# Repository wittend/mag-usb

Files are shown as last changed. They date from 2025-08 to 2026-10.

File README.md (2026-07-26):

# mag-usb

Version: 0.0.9

Official documentation -- https://mag-usb.readthedocs.io/

**mag-usb** is a Linux command‑line utility for reading a PNI RM3100 3‑axis magnetometer via a USB‑to‑I²C adapter (Pololu 5396/5397). It outputs time‑stamped magnetic field vectors and supports optional configuration via a simple TOML file.

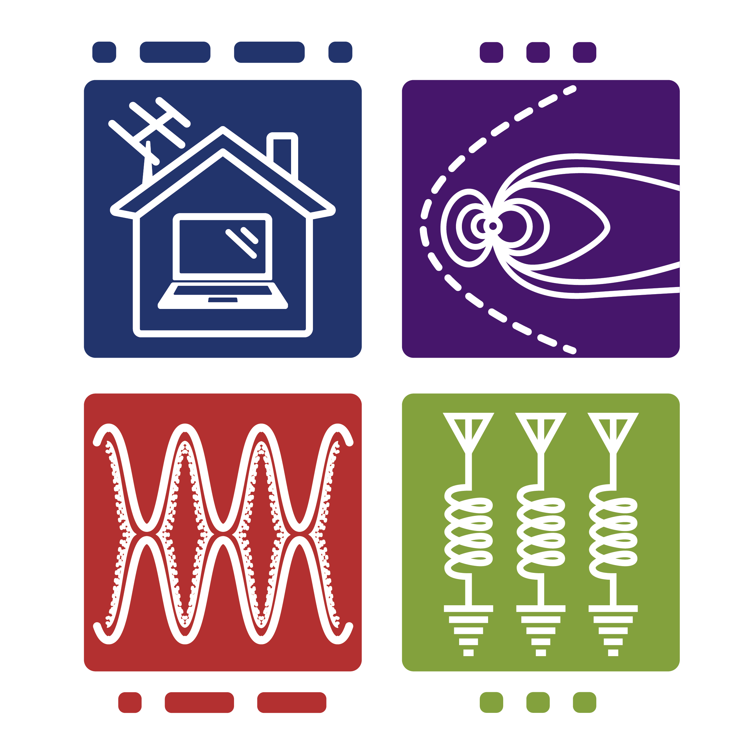
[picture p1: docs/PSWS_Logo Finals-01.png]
HamSCI Project


The RM3100 boards were developed for the HamSCI Personal Space Weather Station (PSWS) TangerineSDR and Grape monitors, but mag-usb can be used as a standalone low‑cost geomagnetic field logger.

Key points:
- Portable C (no heavyweight dependencies).
- Designed to use the Pololu Isolated USB‑to‑I²C Adapter family.
- Works on typical Linux hosts with USB 2.0. Raspberry Pi‑class devices may work but are not the current target.
- Windows is not supported. MacOS is supported through Docker.

## Features
- Reads RM3100 magnetometer X/Y/Z and prints JSON lines including an RFC‑2822 timestamp.
- Configurable cycle counts, gains, and sampling parameters.
- Optional orientation translations in 90° increments about X/Y/Z, set in config.toml.
- Support for concurrent output to `stdout` and named pipes for IPC (local monitoring/dashboards).
- MQTT publication support (1Hz batched JSON) with TLS and authentication.
- Convenience flag to print current settings (`-P`).
- Optional diagnostics: verify devices, scan I²C bus, etc.

## Build (using CMake)

Plain CMake (requires OpenSSL):
```
cmake -S . -B build -DCMAKE_BUILD_TYPE=Release
cmake --build build --target mag-usb
```

Optional WebSocket support (vendored header-only library):
```
cmake -S . -B build -DCMAKE_BUILD_TYPE=Release -DENABLE_WEBSOCKET=ON
cmake --build build --target mag-usb
```

CLion IDE (convenient if you happen to have it):
- Open the project; CLion generates Debug and Release profiles under cmake-build-debug and cmake-build-release.
- Build the target `mag-usb` from the chosen profile.

## Build (using Docker)
Use socat to create a connection to the adapter. Then, start a container:
```
docker compose run --rm host
```

Refer to the [setup documentation](/docs/MacOS-Setup.md) for more details.

## Quick start
- Connect the Pololu USB‑to‑I²C adapter and your RM3100 board.
- Install the udev rule from `install/99-PololuI2C.rules` once per host
  so the adapter consistently appears as `/dev/ttyMAG0` (the new
  default). Without the rule, override with `-O /dev/ttyACM0` (or
  whichever ACM device the adapter enumerated as).
```
./build/mag-usb -Q                # uses /dev/ttyMAG0 by default
./build/mag-usb -O /dev/ttyACM0 -Q  # override if no udev rule
```
Flags shown here:
- `-O` sets the adapter device path.
- `-Q` verifies adapter presence.

To print current settings (and exit):
```
./build/mag-usb -P
```
The program follows Linux filesystem conventions and looks for its configuration file in the following order:
1. `/etc/mag-usb/config.toml`
2. `config.toml` in the current working directory.

If neither is found, reasonable default values are used. Command-line arguments always overrule both default values and those found in any configuration file.

## Configuration
A simple TOML configuration file is supported. The program searches for it in `/etc/mag-usb/config.toml` first, then in the local directory. See:
- docs/Configuration.md — all keys, defaults, and examples.
- docs/Orientation-and-Axes.md — how the 90° orientation translations work.

Example orientation section:
```
[mag_orientation]
mag_translate_x = 90
mag_translate_y = 0
mag_translate_z = -90
```
Allowed values: `-180, -90, 0, 90, 180` (±180 are equivalent). Invalid/missing values default to 0.

## Output format
Each line is JSON with at least:
```
{ "ts": "DD Mon YYYY HH:MM:SS", "rt": NN.NNN, "x": NNN.NNN, "y": NNN.NNN, "z": NNN.NNN }
```
- Units: nanoTesla (nT)
- Orientation translations are applied before printing.
See docs/Data-Format.md for more detail.

## Running tests (CTest)
The `i2c-pololu` unit tests are integrated with CTest.

Enable/Build/Run:
```
cmake -S . -B build -DBUILD_TESTING=ON
cmake --build build --target i2c-pololu-tests
(cd build && ctest --output-on-failure)
```
Run the test executable directly:
```
./build/i2c-pololu-tests
```

## Documentation
- Getting Started: docs/Getting-Started.md
- Configuration reference: docs/Configuration.md
- MQTT Testing Tools: tools/mqtt_listener.c, tools/mqtt_command.c
- Orientation and axes: docs/Orientation-and-Axes.md
- Data format: docs/Data-Format.md
- Hardware Setup (wiring, udev rules): docs/Hardware-Setup.md
- Requirements: docs/Requirements.md
- Troubleshooting: docs/Troubleshooting.md
- Project Review: docs/Code-Review-and-Critique-2026-05-15-by-gemini-3-flash-preview.md
- Development guide: docs/Development.md
- Contributors: docs/Contributors.md
- Contribution guidelines: CONTRIBUTING.md

## Command‑line help
```
./mag-usb -h
```
You should see something similar to:
```
Parameters:

   -B <reg mask>          :  Do built in self test (BIST).         [ Not implemented ]
   -C                     :  Read back cycle count registers before sampling.
   -c <count>             :  Set cycle counts as integer.          [ default: 200 decimal]
   -D <rate>              :  Set magnetometer sample rate.         [ TMRC reg 96 hex default ].
   -g <mode>              :  Device sampling mode.                 [ POLL=0 (default), CONTINUOUS=1 ]
   -O                     :  Path to Pololu port in /dev.          [ default: /dev/ttyACM0 ]
   -P                     :  Show all current settings and exit.
   -Q                     :  Verify presence of Pololu adaptor.
   -S                     :  List devices seen on i2c bus and exit.
   -T                     :  Verify Temperature sensor presence and version.
   -u                     :  Use named pipes for output.
   -i <path>              :  Path for input named pipe.
   -o <path>              :  Path for output named pipe.
   -V                     :  Display software version and exit.
   -h or -?               :  Display this help.
```

## Contributors
- **Dave Witten, KD0EAG** - Lead developer and maintainer.
- **Michael Hauen** - Contribution to sample reliability and code quality.
- **Jackson Conti** - Core contributions and implementation.
- **Bill Engelke** - Improvement to output timing and cadence.
- **Dave Larsen** - Formatting and JSON output enhancements.
- **Rob** - Integration and system testing support.
- **Claude (AI)** - Code reviews and project architecture guidance.
- **Gemini (AI)** - Development of MQTT capabilities, documentation, and technical critiques.

## Pololu adapter links
- https://www.pololu.com/product/5397
- https://www.pololu.com/product/5396

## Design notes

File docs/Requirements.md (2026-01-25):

# mag-usb Requirements

This document defines the functional, non-functional, and delivery requirements for a clean-room reimplementation of the mag-usb project.
It is a specification document, not an implementation guide.
It is intended as a start-to-finish blueprint: hardware, software, build, runtime behavior, and documentation.

## 1. Scope and goals
- Provide a Linux command-line utility that reads a PNI RM3100 3-axis magnetometer via a Pololu USB-to-I2C adapter.
- Emit time-stamped magnetic field vectors in a JSON-lines format for downstream ingestion.
- Support a simple TOML configuration file, with command-line overrides.
- Provide lightweight diagnostics (adapter check, I2C bus scan, sensor presence checks).
- Keep implementation portable C (C11) with minimal dependencies.

Non-goals:
- Windows support.
- Arbitrary-angle orientation or full magnetometer calibration (soft/hard iron compensation).
- GUI or web interface.

## 2. Supported platforms and environment
- Target OS: Linux.
- Expected device nodes: USB CDC ACM (`/dev/ttyACM*`).
- macOS: untested and optional.
- SBCs (Raspberry Pi class): not primary target; use Pololu adapter instead of native GPIO/I2C libraries.

## 3. Hardware requirements
- Pololu Isolated USB-to-I2C Adapter:
  - Product 5396 or 5397.
- RM3100-based magnetometer board.
- Wiring:
  - SDA to SDA, SCL to SCL, GND to GND, optional +5V if required by board.
  - Confirm I2C pull-ups exist.
- Optional: MCP9808 temperature sensor for remote temperature readings.

## 4. System behavior and functional requirements

### 4.1 Program startup
- Load defaults for all parameters.
- Load configuration file from:
  1) `/etc/mag-usb/config.toml`
  2) `config.toml` in current working directory
- If the first file fails to load or does not exist, fall back to local file.
- Ignore or clamp invalid config values to defaults.
- Parse command-line arguments after config load; CLI overrides config and defaults.
- If `-P` is passed, print active settings and exit before hardware initialization.

### 4.2 Command-line interface (CLI)
Provide the following options:
- `-B <reg mask>`: BIST (not implemented, but option exists).
- `-C`: read back cycle count registers before sampling.
- `-c <count>`: set cycle count for X/Y/Z; valid range 1..800 (decimal).
- `-D <rate>`: set CMM sample rate (integer).
- `-g <mode>`: sampling mode (POLL=0, CMM=1).
- `-O <path>`: Pololu adapter device path (default `/dev/ttyACM0`).
- `-P`: show current settings and exit.
- `-Q`: verify Pololu adapter presence and exit.
- `-M`: verify magnetometer presence and version and exit.
- `-S`: scan I2C bus and exit.
- `-T`: verify temperature sensor presence and version and exit.
- `-u`: enable named pipes for output.
- `-i <path>`: input named pipe path.
- `-o <path>`: output named pipe path.
- `-V`: print version and exit.
- `-h`/`-?`: print help and exit.

### 4.3 I2C adapter handling
- Verify adapter availability at the configured device path with timeout.
- Validate adapter is a supported Pololu device.
- If adapter is missing or invalid, exit with a clear error.
- If `-Q` is set, only validate adapter and exit 0/1.

### 4.4 Sensor handling
- Support RM3100 magnetometer at a configurable I2C address (default from build config).
- Support MCP9808 temperature sensor at configurable I2C address (default 0x1F).
- Provide diagnostic checks:
  - `-M`: verify magnetometer.
  - `-T`: verify temperature sensor.
  - `-S`: scan I2C bus and report devices.
- Initialize magnetometer registers before sampling.

### 4.5 Sampling and output
- Primary data output: JSON lines, one per sample.
- Output schema:
  - `ts` (string): UTC timestamp, format `DD Mon YYYY HH:MM:SS` (RFC-2822-like without timezone).
  - `rt` (number): remote temperature in deg C.
  - `x`, `y`, `z` (number): magnetometer values in nT, formatted with 3 decimal places.
- Convert RM3100 raw counts to microTesla then multiply by 1000 to nT.
- Apply orientation rotations (see 4.6) before output.
- Log and diagnostic messages may be interleaved with JSON lines on the same stream.

### 4.6 Orientation rotations
- Support 90-degree increments about X, Y, Z axes using right-hand rule.
- Allowed values: -180, -90, 0, 90, 180.
- Apply rotations in order X, then Y, then Z.
- Invalid values fall back to 0.

### 4.7 Named pipes and logging
- If `use_pipes` is enabled or `-u` flag is provided:
  - Create FIFOs if missing with mode 0666.
  - Default paths (from sample config):
    - Input: `/run/mag-usb/magctl.fifo`
    - Output: `/run/mag-usb/magdata.fifo`
  - Open output pipe as non-blocking write, input as non-blocking read.
- If `write_logs` is enabled:
  - Write JSON lines to log files in `log_output_path`.
  - Create directory if `create_log_path_if_empty` is true.

### 4.8 WebSocket output (optional)
- Provide a build flag `ENABLE_WEBSOCKET` to include WebSocket server support.
- When enabled and configured, broadcast each JSON output line to all connected clients.
- Allow runtime configuration of bind address and port.
- Accept multiple concurrent clients; send text frames.

### 4.9 Configuration keys
TOML sections and keys to support:

[node_information]
- `maintainer` (string)
- `maintainer_email` (string)

[node_location]
- `latitude` (string)
- `longitude` (string)
- `elevation` (string)
- `grid_square` (string)

[i2c]
- `use_I2C_converter` (bool)
- `portpath` (string)
- `bus_number` (int)
- `scan_bus` (bool)

[magnetometer]
- `address` (int, decimal or hex)
- `cc_x`, `cc_y`, `cc_z` (int)
- `gain_x`, `gain_y`, `gain_z` (double)
- `tmrc_rate` (int, decimal or hex)
- `nos_reg_value` (int)
- `drdy_delay` (int)
- `sampling_mode` (string "POLL" or "CMM")
- `cmm_sample_rate` (int)
- `readback_cc_regs` (bool)

[mag_orientation]
- `mag_translate_x`, `mag_translate_y`, `mag_translate_z` (int)

[temperature]
- `remote_temp_address` (int, decimal or hex)

[output]
- `write_logs` (bool)
- `log_output_path` (string)
- `create_log_path_if_empty` (bool)
- `use_pipes` (bool)
- `pipe_in_path` (string)
- `pipe_out_path` (string)

[websocket]
- `enable` (bool)
- `bind_address` (string)
- `port` (int)

## 5. Non-functional requirements
- Language: C11; avoid compiler-specific extensions without guards.
- Dependencies: none beyond standard POSIX/Linux system libraries.
- Build tooling: CMake 3.22+.
- Warnings: build with `-Wall -Wextra -Wpedantic`; allow optional `-Werror`.
- Runtime stability: exit with meaningful error messages for adapter/sensor failures.
- Performance: stable sampling, acknowledging jitter from host scheduling and JSON printing.

## 6. Build, test, and packaging

### 6.1 Build
- Provide a top-level `CMakeLists.txt`.
- Build targets:
  - `mag-usb` (main CLI).
  - `i2c-pololu-tests` (unit tests).
- Provide Debug/Release builds via CMake or IDEs (e.g., CLion).

### 6.2 Tests
- Integrate unit tests with CTest.
- Command line:
  - `cmake -S . -B build -DBUILD_TESTING=ON`
  - `cmake --build build --target i2c-pololu-tests`
  - `(cd build && ctest --output-on-failure)`

### 6.3 Installation artifacts
- Include a sample `config.toml`.
- Provide udev rule for Pololu adapter in `install/99-PololuI2C.rules`.
- Document installation of udev rule and permissions.

## 7. Documentation deliverables
Required documentation pages:
- Getting started and build steps.
- Hardware wiring and udev setup.
- Configuration reference and examples.
- Output data format.
- Orientation and axes explanation.
- Troubleshooting guide.
- Development guide (build matrix and coding patterns).

## 8. Acceptance criteria
- Build succeeds with CMake 3.22+ on Linux using GCC or Clang.
- `mag-usb -h` shows all documented CLI flags.
- `mag-usb -P` prints effective configuration values.
- `mag-usb -Q` validates adapter and exits.
- JSON output matches schema and units, with orientation rotations applied.
- Config file parsing and CLI overrides behave as specified.
- Named pipes and logging operate per configuration with correct permissions.
- Unit tests compile and run via CTest.

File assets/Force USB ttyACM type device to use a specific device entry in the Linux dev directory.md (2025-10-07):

## Force USB ttyACM to specific /dev device

Yes, there is a way in Linux to force a USB ttyACM type device to always attach to a specific device file in /dev by using udev rules to create persistent symbolic links This ensures that the device is consistently accessible under a predictable name, regardless of the order in which devices are connected or the system's boot sequence.

To achieve this, you need to create a custom udev rule file in the /etc/udev/rules.d/ directory, such as /etc/udev/rules.d/49-custom.rules The rule should identify the specific USB device using unique attributes like the vendor ID (`idVendor`) and product ID (`idProduct`) obtained from `lsusb` For example, to assign a U-Blox GNSS receiver to a symbolic link named `/dev/ttyGPS`, the rule would be:

```
KERNEL=="ttyACM[0-9]*", SUBSYSTEM=="tty", ATTRS{idVendor}=="1546", ATTRS{idProduct}=="01a8", SYMLINK+="ttyGPS"
```

This rule uses the `SYMLINK` directive to create a persistent symbolic link that points to the actual device file (e.g., `/dev/ttyACM0` or `/dev/ttyACM1`) After creating the rule, reload the udev rules with `udevadm control --reload-rules` and reboot the system to apply the changes Once configured, services or applications can reference the consistent symbolic name (e.g., `/dev/ttyGPS`) instead of relying on the potentially changing `/dev/ttyACM*` name

If multiple devices share the same `idVendor` and `idProduct`, you can use additional unique attributes such as the device's serial number (`ATTRS{serial}`) or its kernel path (`KERNELS`) to distinguish them For instance, using `KERNELS=="1-4:1.0"` can tie the rule to a specific USB port on a hub, ensuring consistent naming even when multiple devices are present

## Elaboration

To force a USB ttyACM device to always appear under a specific name in `/dev`, you can create a **persistent symbolic link** using **udev rules** based on unique device attributes.

### 1. Identify Unique Device Attributes
First, connect the device and use:
```bash
udevadm info --name=/dev/ttyACM0 --attribute-walk
```
Look for stable, unique identifiers such as:
- `idVendor` and `idProduct` (identifies device type)
- `serial` (unique per device)
- `KERNELS` (e.g., `1-4:1.0` — identifies physical USB port)

### 2. Create a udev Rule
Create a rule file:
```bash
sudo nano /etc/udev/rules.d/99-mydevice.rules
```

#### Example Rules:
- **By vendor/product (for single device of this type):**
  ```
  SUBSYSTEM=="tty", KERNEL=="ttyACM[0-9]*", ATTRS{idVendor}=="1546", ATTRS{idProduct}=="01a8", SYMLINK+="ttyGPS"
  ```

- **By serial number (for multiple identical devices):**
  ```
  SUBSYSTEM=="tty", KERNEL=="ttyACM[0-9]*", ATTRS{serial}=="ABC123", SYMLINK+="ttyGPS1"
  ```

- **By physical USB port (assigns name based on plug-in location):**
  ```
  SUBSYSTEM=="tty", KERNEL=="ttyACM[0-9]*", KERNELS=="1-4:1.0", SYMLINK+="ttyGPS"
  ```

### 3. Reload and Test
Apply the rules:
```bash
sudo udevadm control --reload-rules && sudo udevadm trigger
```
Replug the device and verify:
```bash
ls -l /dev/ttyGPS
```

### Key Notes:
- Use `SYMLINK+="name"` to create a persistent alias like `/dev/ttyGPS`.
- For multiple similar devices, **use `serial` or `KERNELS`** to avoid conflicts.
- The rule file should end with `.rules` and ideally start with a high number (e.g., `99-`) to ensure it runs last.
- Ensure the file has a trailing newline and is owned by root.

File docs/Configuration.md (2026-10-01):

# Configuration

mag-usb reads an optional `config.toml` at startup. It searches for the configuration file in the following order:
1. `/etc/mag-usb/config.toml` 
2. `config.toml` in the current working directory.

If neither file is found, defaults are used. Invalid values are ignored or reduced to defaults. Command-line arguments always override both default values and those found in any configuration file.

Tip: Run `./mag-usb -P` to print the active settings and exit.

## File format
- Syntax: TOML (key = value). Lines beginning with `#` are comments.
- Sections use `[section_name]` headers.
 
## Sections and keys
Below is the complete reference of supported sections/keys, their types, defaults, and notes.

### [node_information]
- `maintainer` (string)
- `maintainer_email` (string)

Defaults: empty strings.

### [node_location]
- `latitude` (string) — free‑form (e.g., "38.92263").
- `longitude` (string)
- `elevation` (string) — free‑form (e.g., "230 m").
- `grid_square` (string) — e.g., "EM38uw".

Defaults: empty strings.

### [i2c]
- `use_I2C_converter` (bool) — Use Pololu USB‑to‑I²C adapter. Default: true (when built with USE_POLOLU=TRUE).
- `portpath` (string) — Adapter device path. Default: `/dev/ttyMAG0` (created by `install/99-PololuI2C.rules`; falls through to a bare `/dev/ttyACM*` if the udev rule is not installed and `-O` is not supplied).
- `bus_number` (int) — Linux I²C bus number for non‑Pololu setups. Default: 1.
- `scan_bus` (bool) — Probe for devices on startup. Default: false.

Notes:
- If `use_I2C_converter=true`, `portpath` must be accessible to the process (see udev notes in Hardware‑Setup.md).

### [magnetometer]
- `address` (int, decimal or hex `0xNN`) — RM3100 I²C address. Default: build‑time default from `RM3100_I2C_ADDRESS`.
- `cc_x`, `cc_y`, `cc_z` (int) — Cycle counts. Typical values: 200, 400. Default: 400 (if set in config.toml).
- `gain_x`, `gain_y`, `gain_z` — No longer used. The gain is derived from each axis's cycle count (`gain = 0.3671 × CC + 1.5`, e.g. 148.34 at CC 400), so it always matches what the sensor is programmed with. If these keys are present, a warning is printed and they are ignored.
- `tmrc_rate` (int, decimal or hex) — TMRC register value. Default: 0x96.
- `nos_reg_value` (int) — Number‑of‑samples register value. Default: 60.
- `drdy_delay` (int) — Sleep between DRDY-poll iterations in **milliseconds**. Default: 10. (The implementation passes `drdy_delay * 1000` to `usleep()`, which takes microseconds; the configured value is therefore an `ms` count, not a `µs` count.)
- `sampling_mode` (string) — `"POLL"` or `"CMM"`. Default: `"POLL"`.
- `cmm_sample_rate` (int) — CMM sample rate (Hz). Default: 400.
- `readback_cc_regs` (bool) — Read back CC registers after setting. Default: false.

### [mag_orientation]
Defines fixed 90°‑increment rotations applied to the measured vector before printing.
- `mag_translate_x` (int) — Allowed values: -180, -90, 0, 90, 180.
- `mag_translate_y` (int) — Allowed values: -180, -90, 0, 90, 180.
- `mag_translate_z` (int) — Allowed values: -180, -90, 0, 90, 180.

Rules:
- Missing/invalid values default to 0.
- `180` and `-180` are treated equivalently.
- Rotations are applied in the order X, then Y, then Z, using right‑hand rule conventions.
- See Orientation-and-Axes.md for visuals and examples.

### [temperature]
- `remote_temp_address` (int, decimal or hex) — MCP9808 temperature sensor address. Default: 0x1F.

### [mqtt]
- `enable` (bool) — Enable MQTT publication. Default: false.
- `broker_address` (string) — MQTT broker host. Default: `localhost`.
- `broker_port` (int) — MQTT broker port. Default: 8883.
- `username` (string) — Optional username.
- `password` (string) — Optional password.
- `topic` (string) — Publication topic. Default: `mag-usb/data`.
- `client_id` (string) — Client ID. Default: `mag-usb-client`.
- `use_tls` (bool) — Use secure TLS (mqtts://). The broker's certificate is verified, and the connection is refused if verification fails. Default: true.
- `ca_file` (string) — Path to a PEM CA certificate (or bundle) used to verify the broker. Empty uses the system trust store, which covers brokers with certificates from a public CA. Set it for a self-signed or private-CA broker. Default: empty.

TLS verification also checks that the broker's certificate names the host in `broker_address`: a DNS name is matched against the certificate's DNS names, and an IP address against its IP addresses. If the connection fails, the error printed on stderr says why (for example `unable to get local issuer certificate` means the CA isn't trusted, so set `ca_file`).

Note: Credentials (username/password) are never included in the JSON configuration messages published to the topic.
Commands like `get_config` can be sent to `<topic>/command` to trigger a re-broadcast of the current settings.

### [output]
- `write_logs` (bool) — Write logs to files. Default: false.
- `log_output_path` (string) — Path for log files. Default: `./logs` (when logging enabled).
- `create_log_path_if_empty` (bool) — Create `log_output_path` if missing. Default: true.
- `use_pipes` (bool) — Use named pipes for IPC. Default: false.
- `pipe_in_path` (string) — Path to control pipe (writer side). Default: `/run/mag-usb/magctl.fifo`.
- `pipe_out_path` (string) — Path to data pipe (reader side). Default: `/run/mag-usb/magdata.fifo`.

Note: When `use_pipes=true`, the program will create the pipes if they do not exist with `0666` permissions.

### [websocket]
- `enable` (bool) — Enable the WebSocket output server. Default: false.
- `bind_address` (string) — Server bind address. Default: `0.0.0.0`.
- `port` (int) — Server port. Default: 8765.
Note: This section is active only when built with `-DENABLE_WEBSOCKET=ON`.

## Example
```toml
# mag-usb Configuration File
# Lines starting with # are comments.
# Inline comments (Data followed by hashmark) not allowed.
[node_information]
maintainer = "Dave Witten, KD0EAG"
maintainer_email = "wittend@wwrinc.com"

[node_location]
# Tools:
#   lat/long: Google Maps or GNSS device.
#   Altitude: Optional, or Use GNSS device, or find yourself in Google Earth and look at the status bar at the bottom.
#   Grid square conversion: https://www.giangrandi.org/electronics/radio/qthloccalc.shtml or similar.
latitude = "38.92263"
longitude = "-92.29831"
elevation = "230 M"
grid_square = "EM38uw"

[output]
# Write logfiles to log_output_path..
write_logs = false
# create logfiles in this location.
log_output_path = "./logs"
# create this location if it does not esist.
create_log_path_if_empty = true

# Use named pipes for IPC.
use_pipes = false
# Pipe paths (if use_pipes is true).
pipe_in_path = "/run/mag-usb/magctl.fifo"
pipe_out_path = "/run/mag-usb/magdata.fifo"

[websocket]
# Enable WebSocket output server.
enable = false
# Bind address and port for WebSocket clients.
bind_address = "0.0.0.0"
port = 8765

[i2c]
# Use external USB to I2C device.
use_I2C_converter = true
# Path to the I2C device.
portpath = "/dev/ttyMAG0"
# I2C bus number (for non-Pololu setups).
bus_number = 1
# Scan I2C bus on startup.
scan_bus = false

[magnetometer]
# Magnetometer I2C address (hex format supported).
address = 0x23
# Cycle Count registers (200 or 400 typically).
cc_x = 400
cc_y = 400
cc_z = 400
# Gain is derived from the cycle count: gain = 0.3671 * CC + 1.5.
# TMRC Rate register value (hex format).
tmrc_rate = 0x96
# Number of samples register value.
nos_reg_value = 60
# DRDY delay in milliseconds (passed to usleep as ms * 1000).
drdy_delay = 10
# Sampling mode: "POLL" or "CMM".
sampling_mode = "POLL"
# CMM sample rate (Hz)
cmm_sample_rate = 400
# Read back cycle count registers after setting.
readback_cc_regs = false

# Magnetometer Orientation in degrees relative to default (See hardware setup docs).
# Plus and minus 180 are equivalent. Plus and minus 90 are different!
[mag_orientation]
# Allowed values: -180, -90, 0, 90, 180
mag_translate_x = 0
mag_translate_y = 0
mag_translate_z = 0

[mqtt]
# Enable MQTT publication.
enable = false
# Broker address and port (use 8883 for TLS/MQTTS).
broker_address = "localhost"
broker_port = 8883
# Optional credentials.
username = ""
password = ""
# Topic for data publication.
topic = "mag-usb/data"
client_id = "mag-usb-client"
# Use secure TLS (mqtts://). The broker's certificate is verified.
use_tls = true
# CA certificate for a self-signed or private-CA broker (empty = system trust store).
ca_file = ""

[temperature]
# Remote temperature sensor I2C address
remote_temp_address = 0x1F
```

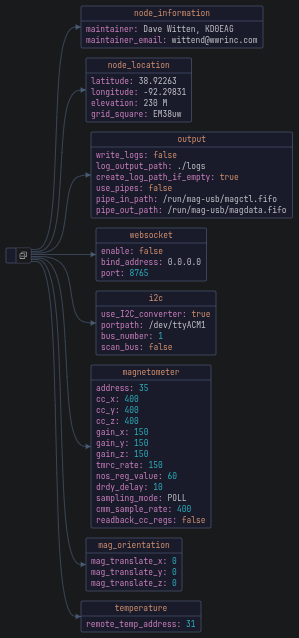
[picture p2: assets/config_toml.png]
Configuration Example

*Fig. 3: Sample config.toml file for mag-usb.*

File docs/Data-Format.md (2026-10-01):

# Data Format

mag-usb prints one JSON object per line to OUTPUT_PRINT. Each line represents a single sample of the magnetometer vector (and optionally other values in the future).

## Baseline schema
```
{ "ts": "DD Mon YYYY HH:MM:SS", "rt": <float>, "x": <float>, "y": <float>, "z": <float> }
```
- `ts` (string): UTC timestamp formatted like `25 Oct 2025 14:02:33` (RFC‑2822‑like time portion without timezone offset).
- `rt` (number): Value of temperature measured in degree C of the sensor at its 'remote' location. 
- `x`, `y`, `z` (number): Field components in nanoTesla (nT), with 3 decimal places printed.

Example:
```
{ "ts":"26 Oct 2025 14:20:00", "rt":23.125, "x":12345.678, "y":-234.500, "z":987.001 }
```

## Units and scaling
- Raw RM3100 counts are converted using the gain for each axis's cycle count (`gain = 0.3671 × CC + 1.5`) and the `NOS` (number‑of‑samples) register value.
- Outputs are provided in nanoTesla (nT). Internally the computation converts microTesla to nanoTesla by multiplying by 1000.

## Orientation translations
If configured, 90° increment rotations are applied to `(x,y,z)` before printing. See `docs/Orientation-and-Axes.md` and `[mag_orientation]` in `docs/Configuration.md`.

## Precision and rounding
- Values are printed with `%.3f` (three digits after decimal). This does not imply instrument accuracy; it is a display choice.

## Sampling cadence
- In POLL mode, each call to `formatOutput()` prints one sample.
- In CMM mode (continuous), the sample rate is controlled by `cmm_sample_rate`; see `docs/Configuration.md`.

## Errors and diagnostics output
- Informational and error messages (e.g., adapter checks) are printed to OUTPUT_PRINT/ around the JSON lines. If you need a clean stream of JSON only, redirect  and/or prefilter lines not starting with `{`.

## MQTT Message Formats

When MQTT is enabled, two types of messages are published to the configured topic.

### 1. Telemetry Data (1Hz Batched)
By default, sensor readings are batched and published once per second to minimize network overhead and avoid timing overlaps.
```json
{
  "ts": "26 Jul 2026 14:20:01",
  "rt": 23.125,
  "x": 12345.678,
  "y": -234.500,
  "z": 987.001
}
```

### 2. Configuration Message
Published automatically on connection, and whenever a `get_config` command is received on the `<topic>/command` sub-topic.
```json
{
  "msg_type": "config",
  "version": "0.0.9",
  "maintainer": "Dave Witten, KD0EAG",
  "location": {
    "lat": "38.92263",
    "lon": "-92.29831",
    "grid": "EM38uw"
  },
  "mqtt_settings": {
    "broker": "test.mosquitto.org",
    "port": 8883,
    "topic": "mag-usb/data",
    "tls": true
  }
}
```
**Note:** Sensitive information such as the MQTT password is never included in the configuration message.

## Logging and pipes
- If you enable logging or named pipes in the configuration, the same JSON lines are written to files or pipes. 
- Named pipes (FIFOs) allow real-time IPC with local monitor/dashboard programs.
- Default pipe paths are `/run/mag-usb/magctl.fifo` (input) and `/run/mag-usb/magdata.fifo` (output).
- See `docs/Configuration.md` (output section) for details.

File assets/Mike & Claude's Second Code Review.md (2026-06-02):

## Second Claude Code Review for mag-usb. 
Focused on the scaling and configuration issues that have been observed in live data.

1. [**Note**: This is a follow-up to the first Claude code review, which focused on code quality and maintainability. This review focuses on correctness and operator experience.]
2. [**Note**: A second review using the Gemini model was performed to examine standalone code quality and maintainability, without the context of the live data issues. That review is documented separately.]
3. [**Note**: This represents feedback within a team consisting of three humans: Mike, Rob, and Dave.  Dave is the author of the code under review, and Rob is a third team member working with Mike. Claude, Gemini, and their friends are AI Assistants.  Claude is providing objective feedback. Dave is also being assisted by one of more AI tools.]
4. [**Note**: Mike, Rob, and Claude are working together to integrate this program (mag-usb) into a larger system (sigmond), that may also incorporate other components (mag-recorder, magrec, a global installation process, etc.) when used with sigmond.]
5. [**Note**: mag-usb must also retain the ability to be configured independently.]
6. [**Note**: The tone is collaborative and constructive, with a focus on improving the code and the operator experience.]

### PR-1: drop the spurious /NOSRegValue factor in POLL-mode scaling

src/main.c:606-608:
* xyz[0] = (((double)p->XYZ[0] / p->NOSRegValue) / p->x_gain) * 1000;
* The PNI formula Dave himself pasted into src/magdata.c:142-148 is µT = raw / (0.3671·CC + 1.5), no NOS term. With NOSRegValue defaulting to 60, every reported value is off by ~60× — that's exactly what live data on my desk shows (-210..+412
where Earth-field axis components should be 10,000–30,000 nT). NOS only belongs in the scaling for CMM-with-averaging, where the chip has been programmed to sum N samples internally; in single-shot POLL mode the chip already returns per-sample values. 
* Suggested fix: drop the /NOSRegValue. If Dave wants to keep an averaging path for a future CMM mode, gate it on p->samplingMode == CMM and only when the chip's NOS register has actually been written.

### PR-2: actually program the chip's CC and NOS registers (or remove the knobs)

src/magdata.c:166-180 (setCycleCountRegs) 
* has every i2c_write commented out. 
* Same in setNOSReg at magdata.c:106-114: 
    * the whole body is dead. Net effect: cc_x/y/z and NOSRegValue in config are host-side ghosts. The chip stays at power-on
defaults (CC=200/axis), and any operator who edits cc_x = 400 in tools/config.toml thinks they've doubled their sensitivity but actually they've just made the host divide by a bigger number. This is upstream of the magnitude bug in PR-1 — both
fixes are needed.

Chosen approach:
* Restore the writes using the Pololu I²C path (the rest of the I/O in this binary already does this), so config takes effect. Cleaner long-term.
* **Make note** in _documentation_ and _comment in code_: "[**Path not taken**]: remove the host-side CC/NOS knobs entirely, hard-code gain from chip defaults, and document that. Smaller patch, less flexible."

Either is fine; the current limbo is what's broken.

### PR-3: fix the example tools/config.toml

tools/config.toml ships cc_x = cc_y = cc_z = 400
* This combined with PR-2 silently mis-scales. After PR-2 lands this becomes a correctness fix or a delete-the-knob change, depending on which path Dave picks.

* mag-usb layering PRs (so mag-recorder can fully own operator config)

* The pattern I'd like to align with: mag-recorder is the program the operator configures; mag-usb is the sensor driver mag-recorder drives. Operator never sees /etc/mag-usb/anything. All knobs live in /etc/mag-recorder/mag-recorder-config.toml.

### PR-4: accept config-file path on the CLI

src/main.c currently auto-discovers /etc/mag-usb/config.toml then ./config.toml, with no way to point it elsewhere. 
* Make it accept -f <path> (or --config <path> if Dave wants to move to getopt_long) — note -c is already taken by cycle-count.
* When -f is given, skip the auto-discovery entirely so the binary's behavior is fully determined by argv. 
    - mag-recorder will then render a private TOML at /etc/mag-recorder/mag-usb-driver.toml and pass it explicitly.

Optional sweetener: also accept -A <hex> (single-knob address override) for the common case of "everything else default, just point at 0x23." Saves a config file in the hand-debug workflow.

### PR-5: make -P (show settings) print chip state, not host state

Today -P prints the host's intended values. After PR-2 those should match the chip, but a real -P that reads back the CC/NOS/TMRC registers would catch any future regression where the writes silently stop landing. Small but high-leverage.

What this lets mag-recorder do (no Dave work, just queued on our side)

1. Render /etc/mag-recorder/mag-usb-driver.toml as an install step — sourced from [mag] keys in mag-recorder-config.toml. Operator never edits the driver TOML.
2. Patch supervisor.py:_mag_usb_source to construct argv = [binary, "-O", device, "-f", "/etc/mag-recorder/mag-usb-driver.toml"]. The currently-dangling mag_usb_config key in mag-recorder-config.toml finally connects to something.
3. Add an install step that drops install/99-PololuI2C.rules from upstream mag-usb into /etc/udev/rules.d/ and runs udevadm trigger. This is the "predictable device regardless of USB port" piece — /dev/ttyMAG0 becomes the stable symlink
   mag-recorder's config already points at by default.
4. Add magrec to dialout in deploy (already done in the service file's SupplementaryGroups=dialout; confirm the user-creation step also sets it).
5. Strengthen mag-recorder validate to fail loudly when the configured [mag].i2c_address doesn't match what mag-usb -M reports — so an operator with a different carrier-board strapping sees a clear
    validate error instead of a silent NACK at runtime.
Once PR-1+2+4 land in wittend/mag-usb (and we cherry-pick / merge into our sigmond-integration branch):

### PR-6: render /etc/mag-recorder/mag-usb-driver.toml from mag-recorder-config.toml

1. Render /etc/mag-recorder/mag-usb-driver.toml as an install step — sourced from [mag] keys in mag-recorder-config.toml. Operator never edits the driver TOML.
2. Patch supervisor.py:_mag_usb_source to construct argv = [binary, "-O", device, "-f", "/etc/mag-recorder/mag-usb-driver.toml"]. The currently-dangling mag_usb_config key in mag-recorder-config.toml finally connects to something.
3. Add an install step that drops install/99-PololuI2C.rules from upstream mag-usb into /etc/udev/rules.d/ and runs udevadm trigger. This is the "predictable device regardless of USB port" piece — /dev/ttyMAG0 becomes the stable symlink
   mag-recorder's config already points at by default.
4. Add magrec to dialout in deploy (already done in the service file's SupplementaryGroups=dialout; confirm the user-creation step also sets it).
5. Strengthen mag-recorder validate to fail loudly when the configured [mag].i2c_address doesn't match what mag-usb -M reports — so an operator with a different carrier-board strapping sees a clear validate error instead of a silent NACK at
   runtime.
6. Drop /etc/mag-usb/ from documentation entirely — README/PROVENANCE shouldn't mention it once PR-4 lands.

## Suggested order for your conversation with Dave

1. PR-1 (60× scaling — operator-visible correctness; this is the headline)
2. PR-2 (CC/NOS writes — explains why the scaling looks the way it does, and unblocks per-axis tuning)
3. PR-3 (example TOML — trivial follow-on)
4. PR-4 (config-file CLI flag — layering; this is the one that lets mag-recorder act like a proper sigmond client)
5. PR-5 (-P reads chip state — diagnostic hygiene)

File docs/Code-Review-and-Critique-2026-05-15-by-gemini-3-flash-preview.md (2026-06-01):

# Code Review and Critique - 2026-05-15  
### Project Critique and Code Review: `mag-usb`
###   by gemini-3-flash-preview
This document contains a comprehensive review of the `mag-usb` project performed on May 15, 2026, covering source code, build system, test suite, and documentation.

#### 1. Code Quality and Architecture
*   **Robust I²C Implementation**: The `i2c-pololu.c` module is exceptionally well-structured. It implements the Pololu binary protocol with clear error handling, device validation, and state management. The use of a mock device thread in tests demonstrates a high level of technical maturity.
*   **Thread Safety and Signals**: The project correctly uses POSIX threads (`pthreads`) and handles signals (`sigaction`, `sigwait`) to ensure graceful shutdowns. Blocking signals in worker threads and handling them in a dedicated thread is a best-practice pattern.
*   **Memory Management**: Strings parsed from the configuration are handled via `strdup` and freed in `free_config_strings`, indicating good hygiene regarding heap allocations.
*   **Configuration Parsing**: The custom TOML parser in `src/config.c` is functional and tailored to the project's needs. While it doesn't support the full TOML spec (e.g., nested tables or arrays), it is perfectly adequate for the current requirements.

#### 2. Build System and Portability
*   **Modern CMake**: The `CMakeLists.txt` is clean and follows modern practices. It uses `target_include_directories` and `target_compile_definitions` properly. The inclusion of `_GNU_SOURCE` and `_DEFAULT_SOURCE` ensures portability across Linux distributions.
*   **Conditional Features**: WebSocket support is correctly handled as an optional feature using CMake options and preprocessor definitions.
*   **Warning Hygiene**: Building with `-Wall -Wextra -Wpedantic` and having an `ENABLE_WERROR` option shows a commitment to code quality.

#### 3. Documentation
*   **Comprehensive Coverage**: The documentation in `docs/` is excellent. It covers everything from hardware wiring and udev rules to data formats and orientation theory.
*   **Visual Context**: The integration of images into the Markdown files significantly improves usability, especially for the hardware setup and troubleshooting sections.
*   **Consistency**: The `README.md` and the sub-docs are consistent in their instructions and reflect the current state of the CLI.

#### 4. Testing
*   **Effective Unit Tests**: The `i2c-pololu-tests` provide good coverage of the adapter communication logic. The use of `socketpair` to simulate a serial device is an elegant way to test hardware-interfacing code without physical hardware.
*   **Stability**: The tests pass reliably and include safety measures like an overall timeout (`alarm(30)`) to prevent hangs during CI/CD.

#### 5. Minor Observations / Areas for Improvement
*   **Configuration Path**: Currently, the program checks `/etc/mag-usb/config.toml` and then the local directory. Adding a flag to specify a custom config file path (e.g., `-c <path>`) would be a useful future enhancement.
*   **Inline Comments in TOML**: The parser currently ignores lines starting with `#` but might not handle inline comments (e.g., `key = value # comment`). This is noted in the documentation as a limitation.
*   **Hardware Defaults**: The code relies on some external `extern` variables for defaults (e.g., `CC_400`). Ensuring these are consistently initialized across all build profiles is important.

### Conclusion
The project is in a **very healthy state**. The code is professional, the build system is robust, the tests are effective, and the documentation is top-tier for an open-source utility.

**Review Result:** ✅ **Ready to commit and push.**

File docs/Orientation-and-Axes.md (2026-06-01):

# Orientation and Axes

This document explains how mag-usb handles magnetometer orientation and how to configure 90° rotations around each axis.

## Axis conventions
- The RM3100 outputs three orthogonal components X, Y, Z.
- mag-usb treats these axes as a right‑handed coordinate system.
- Positive rotations follow the right‑hand rule (thumb points along the axis of rotation; curl of fingers is direction of positive rotation).
 
## Why orientation adjustments?
Depending on how the sensor PCB is mounted in your enclosure, its axes may not align with your desired reference frame. mag-usb can rotate the measured vector by multiples of 90° around the X, Y, and Z axes to align with your installation.

## Configuration
Set the following keys in `config.toml` under `[mag_orientation]`:
```
[mag_orientation]
mag_translate_x = <int>   # -180, -90, 0, 90, 180
mag_translate_y = <int>   # -180, -90, 0, 90, 180
mag_translate_z = <int>   # -180, -90, 0, 90, 180
```
Rules:
- Allowed values: `-180, -90, 0, 90, 180`. Any other value is treated as `0`.
- `180` and `-180` are treated the same (flip both perpendicular axes).
- Rotations are applied in this order: rotate around X, then around Y, then around Z.
- The rotations affect the other two components:
  - Rotate around X → affects Y and Z.
  - Rotate around Y → affects X and Z.
  - Rotate around Z → affects X and Y.

## Examples
Let the input vector be `(X, Y, Z)`.

- Rotate +90° about X:
  - `(X, Y, Z)` → `(X, -Z, Y)`
- Rotate -90° about X:
  - `(X, Y, Z)` → `(X, Z, -Y)`
- Rotate 180° about X:
  - `(X, Y, Z)` → `(X, -Y, -Z)`

- Rotate +90° about Y:
  - `(X, Y, Z)` → `(Z, Y, -X)`
- Rotate -90° about Y:
  - `(X, Y, Z)` → `(-Z, Y, X)`
- Rotate 180° about Y:
  - `(X, Y, Z)` → `(-X, Y, -Z)`

- Rotate +90° about Z:
  - `(X, Y, Z)` → `(-Y, X, Z)`
- Rotate -90° about Z:
  - `(X, Y, Z)` → `(Y, -X, Z)`
- Rotate 180° about Z:
  - `(X, Y, Z)` → `(-X, -Y, Z)`

Compound rotations apply these in order X → Y → Z. For example, X=+90°, Z=-90°:
1) X=+90°: `(X, Y, Z)` → `(X, -Z, Y)`
2) Z=-90°: `(X, -Z, Y)` → `(-(-Z), -X, Y)` → `(Z, -X, Y)`

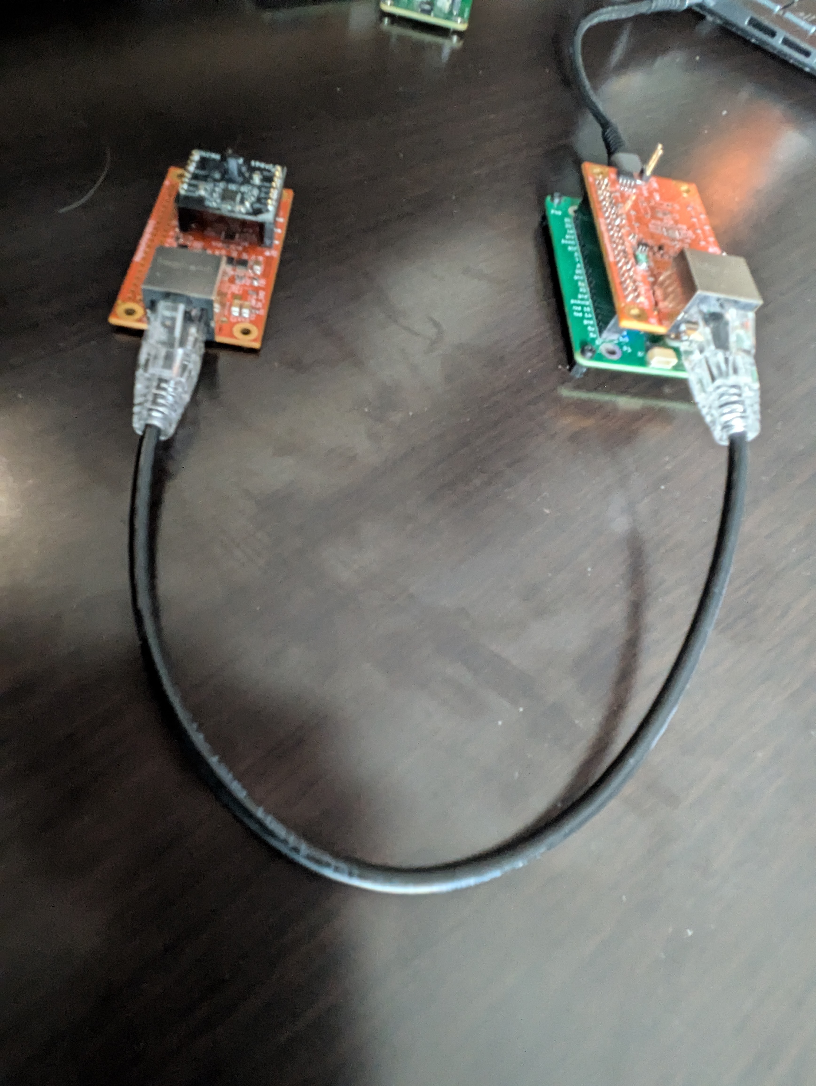
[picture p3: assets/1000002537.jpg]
Coordinate System

*Fig. 7: Magnetometer orientation and axis reference.*

## Verification
After editing `config.toml`, run:
```
./mag-usb -P
```
You should see:
```
Orientation translate (deg XYZ): <x>, <y>, <z>
```
Then start normal sampling and confirm that reported axes behave as expected when you rotate the sensor in known directions.

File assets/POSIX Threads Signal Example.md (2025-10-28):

POSIX Threads Signal Example

Here is a program that uses POSIX threads to print sensor data every 1000 ms and handles standard signals like SIGHUP and SIGABRT using a dedicated signal handling thread:

```c
#include <stdio.h>
#include <stdlib.h>
#include <pthread.h>
#include <signal.h>
#include <unistd.h>
#include <time.h>

// Shared state between threads
volatile sig_atomic_t shutdown_requested = 0; // Signal-safe flag
pthread_mutex_t data_mutex = PTHREAD_MUTEX_INITIALIZER; // Protect shared data
int sensor_data = 0; // Simulated sensor data

// Function to simulate reading sensor data
void* read_sensor(void* arg) 
{
    while (!shutdown_requested) 
    {
        // Simulate sensor reading (replace with actual sensor code)
        sensor_data = rand() % 100; // Random data between 0 and 99

        // Sleep for 1000 ms (1 second)
        usleep(1000000);

        // Check for shutdown request
        if (shutdown_requested) 
        {
            break;
        }
    }
    return NULL;
}

// Function to print sensor data every 1000 ms
void* print_data(void* arg) 
{
    while (!shutdown_requested) 
    {
        // Wait for 1000 ms or until shutdown is requested
        struct timespec ts;
        clock_gettime(CLOCK_REALTIME, &ts);
        ts.tv_sec += 1; // Add 1 second

        // Use condition variable with timeout to wait
        pthread_mutex_lock(&data_mutex);
        int local_data = sensor_data;
        pthread_mutex_unlock(&data_mutex);

        // Print data to OUTPUT_PRINT
        printf("Sensor Data: %d\n", local_data);

        // Sleep for 1000 ms or until interrupted by signal
        struct timespec sleep_time = {1, 0}; // 1 second
        nanosleep(&sleep_time, NULL);
    }

    return NULL;
}

// Signal handler thread function
void* signal_handler_thread(void* arg) 
{
    sigset_t sigset;
    int signum;

    // Block SIGHUP, SIGABRT, and SIGINT in this thread
    sigemptyset(&sigset);
    sigaddset(&sigset, SIGHUP);
    sigaddset(&sigset, SIGABRT);
    sigaddset(&sigset, SIGINT);
    pthread_sigmask(SIG_BLOCK, &sigset, NULL);

    // Wait for any of the blocked signals
    while (1) 
    {
        if (sigwait(&sigset, &signum) == 0) 
        {
            switch (signum) 
            {
                case SIGHUP:
                    printf("Received SIGHUP. Shutting down gracefully.\n");
                    break;
                case SIGABRT:
                    printf("Received SIGABRT. Shutting down gracefully.\n");
                    break;
                case SIGINT:
                    printf("Received SIGINT. Shutting down gracefully.\n");
                    break;
                default:
                    printf("Received unexpected signal %d.\n", signum);
                    break;
            }
            // Set shutdown flag
            shutdown_requested = 1;
            break;
        }
    }
    return NULL;
}

int main() 
{
    pthread_t sensor_thread, print_thread, signal_thread;

    // Create threads
    if (pthread_create(&sensor_thread, NULL, read_sensor, NULL) != 0) 
    {
        perror("pthread_create sensor");
        exit(1);
    }
    if (pthread_create(&print_thread, NULL, print_data, NULL) != 0) 
    {
        perror("pthread_create print");
        exit(1);
    }
    if (pthread_create(&signal_thread, NULL, signal_handler_thread, NULL) != 0) 
    {
        perror("pthread_create signal");
        exit(1);
    }
    // Wait for signal handler thread to complete (it will only return on signal)
    pthread_join(signal_thread, NULL);

    // Signal handler has set shutdown_requested, so wait for other threads to finish
    pthread_join(sensor_thread, NULL);
    pthread_join(print_thread, NULL);

    // Clean up
    pthread_mutex_destroy(&data_mutex);

    printf("Program terminated.\n");
    return 0;
}
```

* This program uses a dedicated signal handling thread to safely receive signals using `sigwait`, which is the recommended approach for multithreaded applications to avoid the pitfalls of signal handlers  
* The main thread creates two worker threads: one to read simulated sensor data and another to print it every 1000 ms. 
* The signal handler thread blocks SIGHUP, SIGABRT, and SIGINT, waits for any of them using `sigwait`, and sets a global `shutdown_requested` flag when a signal is received  
* The worker threads check this flag periodically and terminate gracefully. 
* The main thread waits for the signal handler to complete before joining the other threads and exiting  
* This design ensures safe signal handling in a multithreaded environment

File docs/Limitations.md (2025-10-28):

# Limitations

This document summarizes the expected limitations of mag-usb in its current form (v0.0.3 pre‑release).

## Platform support
- Target platform: Linux.
- Windows: not supported.
- macOS: untested; may work with appropriate serial/tty driver.
- Raspberry Pi and SBCs: may work, but native GPIO/I²C libraries are not used in this build; the Pololu USB‑to‑I²C adapter is the intended path.

## Hardware assumptions
- Designed for the Pololu Isolated USB‑to‑I²C Adapter (5396/5397).
- Requires proper wiring, power, and pull‑ups as per your RM3100 carrier board.

## Sampling modes
- POLL mode is supported.
- CMM (continuous) mode fields exist in configuration; behavior may be limited by adapter throughput and host scheduling.

## Timing and throughput
- JSON printing and host scheduling can introduce jitter. If you need strict timing, consider capturing raw data with a dedicated process and minimal logging.

## Orientation granularity
- Only right‑handed rotations in 90° increments about X/Y/Z are supported via `[mag_orientation]`.
- Arbitrary angles and fine calibration (soft‑/hard‑iron compensation) are not implemented.

## Accuracy and units
- Reported values are in nanoTesla (nT). Display precision is 0.001 nT, which does not imply sensor accuracy.
- Absolute accuracy depends on sensor calibration, installation environment, and configuration (cycle counts, gains).

## Configuration loading
- The program looks for `config.toml` in the current working directory only. If missing or partially invalid, defaults are used silently (warnings may be printed).

## Logging and pipes
- File logging and named pipes are optional features; ensure correct permissions and paths. When disabled, related paths are ignored.

## Error handling
- Some runtime errors print messages interleaved with JSON lines. If you require a clean data stream, redirect  and/or prefilter non‑JSON lines.

## Backward compatibility
- Command‑line flags may evolve; use `-h` to discover current support. Configuration keys not recognized are ignored.

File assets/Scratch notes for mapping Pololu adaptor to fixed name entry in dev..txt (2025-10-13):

# Scratch notes for Dasi2 ProxMox pve (on BeeLink):
#===================================================
#
# Most of this information is from running in the ProxMox >Host< of
#   a newly installed distribution of Proxmox 9.x (Trixie)
#
# The instance that I want to pass a device to is a newly installed
#   instance of Debian (Trixie) running in an LXC >container< under that host.
#
# The goal is to create a >persistent< entry in the client named /dev/ttyMAG0
#   that passes through to the host's USB connection (nominally /dev/ttyACM0)
#      that has the VID/PID '1ffb:2503', Name:
#        'Pololu Corporation Pololu Isolated USB-to-I2C Adapter with Isolated Power'
#      and Serial #" 7300-6100-0150-3642-4837-3020"
# This connection must allways be on the same physical port.
#

# uname -a
#-------------------------
Linux daisy2pve 6.14.11-2-pve #1 SMP PREEMPT_DYNAMIC PMX 6.14.11-2 (2025-09-12T09:46Z) x86_64 GNU/Linux

root@daisy2pve:~# ls /dev/serial/by-id
    usb-Pololu_Corporation_Pololu_Isolated_USB-to-I2C_Adapter_with_Isolated_Power_7300-6100-0150-3642-4837-3020-if00
root@daisy2pve:~# ls -l /dev/serial/by-id
    lrwxrwxrwx 1 root root 13 Oct 10 12:19 usb-Pololu_Corporation_Pololu_Isolated_USB-to-I2C_Adapter_with_Isolated_Power_7300-6100-0150-3642-4837-3020-if00 -> ../../ttyACM0

Bus 001 Device 002: ID 1ffb:2503 Pololu Corporation Pololu Isolated USB-to-I2C Adapter with Isolated Power

# root@daisy2pve:~# lsusb
#--------------------------
Bus 001 Device 001: ID 1d6b:0002 Linux Foundation 2.0 root hub
Bus 001 Device 002: ID 1ffb:2503 Pololu Corporation Pololu Isolated USB-to-I2C Adapter with Isolated Power
Bus 002 Device 001: ID 1d6b:0003 Linux Foundation 3.0 root hub
Bus 003 Device 001: ID 1d6b:0002 Linux Foundation 2.0 root hub
Bus 003 Device 002: ID 046d:c534 Logitech, Inc. Nano Receiver
Bus 003 Device 003: ID 8087:0029 Intel Corp. AX200 Bluetooth
Bus 004 Device 001: ID 1d6b:0003 Linux Foundation 3.0 root hub

# root@daisy2pve:~# lsusb -t
#--------------------------
/:  Bus 001.Port 001: Dev 001, Class=root_hub, Driver=xhci_hcd/4p, 480M
    |__ Port 003: Dev 002, If 0, Class=Communications, Driver=cdc_acm, 12M
    |__ Port 003: Dev 002, If 1, Class=CDC Data, Driver=cdc_acm, 12M
/:  Bus 002.Port 001: Dev 001, Class=root_hub, Driver=xhci_hcd/2p, 10000M
/:  Bus 003.Port 001: Dev 001, Class=root_hub, Driver=xhci_hcd/4p, 480M
    |__ Port 002: Dev 002, If 0, Class=Human Interface Device, Driver=usbhid, 12M
    |__ Port 002: Dev 002, If 1, Class=Human Interface Device, Driver=usbhid, 12M
    |__ Port 003: Dev 003, If 0, Class=Wireless, Driver=btusb, 12M
    |__ Port 003: Dev 003, If 1, Class=Wireless, Driver=btusb, 12M
/:  Bus 004.Port 001: Dev 001, Class=root_hub, Driver=xhci_hcd/2p, 10000M

"1-3:1.0"

    ATTRS{interface}=="Pololu Isolated USB-to-I2C Adapter with Isolated Power"

# Serial #
#-----------------
Dasi2pve:  ATTRS{serial}=="7300-6100-0150-3642-4837-3020"

# For Comparison:
#-----------------
LPSig0:    ATTRS{serial}=="7400-4F00-0150-3642-4837-3020"

# UDEV Walk:
#-----------------
root@daisy2pve:~# udevadm info --name=/dev/ttyACM0 --attribute-walk

Udevadm info starts with the device specified by the devpath and then
walks up the chain of parent devices. It prints for every device
found, all possible attributes in the udev rules key format.
A rule to match, can be composed by the attributes of the device
and the attributes from one single parent device.

  looking at device '/devices/pci0000:00/0000:00:08.1/0000:04:00.3/usb1/1-3/1-3:1.0/tty/ttyACM0':
    KERNEL=="ttyACM0"
    SUBSYSTEM=="tty"
    DRIVER==""
    ATTR{power/async}=="disabled"
    ATTR{power/control}=="auto"
    ATTR{power/runtime_active_kids}=="0"
    ATTR{power/runtime_active_time}=="0"
    ATTR{power/runtime_enabled}=="disabled"
    ATTR{power/runtime_status}=="unsupported"
    ATTR{power/runtime_suspended_time}=="0"
    ATTR{power/runtime_usage}=="0"

  looking at parent device '/devices/pci0000:00/0000:00:08.1/0000:04:00.3/usb1/1-3/1-3:1.0':
    KERNELS=="1-3:1.0"
    SUBSYSTEMS=="usb"
    DRIVERS=="cdc_acm"
    ATTRS{authorized}=="1"
    ATTRS{bAlternateSetting}==" 0"
    ATTRS{bInterfaceClass}=="02"
    ATTRS{bInterfaceNumber}=="00"
    ATTRS{bInterfaceProtocol}=="00"
    ATTRS{bInterfaceSubClass}=="02"
    ATTRS{bNumEndpoints}=="01"
    ATTRS{bmCapabilities}=="6"
    ATTRS{iad_bFirstInterface}=="00"
    ATTRS{iad_bFunctionClass}=="02"
    ATTRS{iad_bFunctionProtocol}=="00"
    ATTRS{iad_bFunctionSubClass}=="02"
    ATTRS{iad_bInterfaceCount}=="02"
    ATTRS{interface}=="Pololu Isolated USB-to-I2C Adapter with Isolated Power"
    ATTRS{physical_location/dock}=="no"
    ATTRS{physical_location/horizontal_position}=="left"
    ATTRS{physical_location/lid}=="no"
    ATTRS{physical_location/panel}=="left"
    ATTRS{physical_location/vertical_position}=="lower"
    ATTRS{power/async}=="enabled"
    ATTRS{power/runtime_active_kids}=="0"
    ATTRS{power/runtime_enabled}=="enabled"
    ATTRS{power/runtime_status}=="suspended"
    ATTRS{power/runtime_usage}=="0"
    ATTRS{supports_autosuspend}=="1"

  looking at parent device '/devices/pci0000:00/0000:00:08.1/0000:04:00.3/usb1/1-3':
    KERNELS=="1-3"
    SUBSYSTEMS=="usb"
    DRIVERS=="usb"
    ATTRS{authorized}=="1"
    ATTRS{avoid_reset_quirk}=="0"
    ATTRS{bConfigurationValue}=="1"
    ATTRS{bDeviceClass}=="02"
    ATTRS{bDeviceProtocol}=="00"
    ATTRS{bDeviceSubClass}=="00"
    ATTRS{bMaxPacketSize0}=="64"
    ATTRS{bMaxPower}=="100mA"
    ATTRS{bNumConfigurations}=="1"
    ATTRS{bNumInterfaces}==" 2"
    ATTRS{bcdDevice}=="0100"
    ATTRS{bmAttributes}=="80"
    ATTRS{busnum}=="1"
    ATTRS{configuration}==""
    ATTRS{devnum}=="2"
    ATTRS{devpath}=="3"
    ATTRS{idProduct}=="2503"
    ATTRS{idVendor}=="1ffb"
    ATTRS{ltm_capable}=="no"
    ATTRS{manufacturer}=="Pololu Corporation"
    ATTRS{maxchild}=="0"
    ATTRS{physical_location/dock}=="no"
    ATTRS{physical_location/horizontal_position}=="left"
    ATTRS{physical_location/lid}=="no"
    ATTRS{physical_location/panel}=="left"
    ATTRS{physical_location/vertical_position}=="lower"
    ATTRS{power/active_duration}=="149848750"
    ATTRS{power/async}=="enabled"
    ATTRS{power/autosuspend}=="2"
    ATTRS{power/autosuspend_delay_ms}=="2000"
    ATTRS{power/connected_duration}=="149848750"
    ATTRS{power/control}=="on"
    ATTRS{power/level}=="on"
    ATTRS{power/persist}=="1"
    ATTRS{power/runtime_active_kids}=="0"
    ATTRS{power/runtime_active_time}=="149848505"
    ATTRS{power/runtime_enabled}=="forbidden"
    ATTRS{power/runtime_status}=="active"
    ATTRS{power/runtime_suspended_time}=="0"
    ATTRS{power/runtime_usage}=="1"
    ATTRS{product}=="Pololu Isolated USB-to-I2C Adapter with Isolated Power"
    ATTRS{quirks}=="0x0"
    ATTRS{removable}=="removable"
    ATTRS{remove}=="(not readable)"
    ATTRS{rx_lanes}=="1"
    ATTRS{serial}=="7300-6100-0150-3642-4837-3020"
    ATTRS{speed}=="12"
    ATTRS{tx_lanes}=="1"
    ATTRS{urbnum}=="227"
    ATTRS{version}==" 2.00"

  looking at parent device '/devices/pci0000:00/0000:00:08.1/0000:04:00.3/usb1':
    KERNELS=="usb1"
    SUBSYSTEMS=="usb"
    DRIVERS=="usb"
    ATTRS{authorized}=="1"
    ATTRS{authorized_default}=="1"
    ATTRS{avoid_reset_quirk}=="0"
    ATTRS{bConfigurationValue}=="1"
    ATTRS{bDeviceClass}=="09"
    ATTRS{bDeviceProtocol}=="01"
    ATTRS{bDeviceSubClass}=="00"
    ATTRS{bMaxPacketSize0}=="64"
    ATTRS{bMaxPower}=="0mA"
    ATTRS{bNumConfigurations}=="1"
    ATTRS{bNumInterfaces}==" 1"

... etc.

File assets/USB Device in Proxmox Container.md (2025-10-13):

## USB Device in Proxmox Container

To make a USB device visible in `/dev` within a Proxmox LXC container running Debian Trixie, you need to pass through the device using the container's configuration. The most reliable method involves using persistent device paths like `/dev/serial/by-id` or directly passing the device via its major and minor numbers.

First, identify the USB device on the Proxmox host using `lsusb` to find the vendor and product IDs, and then use `ls -l /dev/serial/by-id` to find the stable symlink path (e.g., `usb-FTDI_FT230X_Basic_UART_D307ORET-if00-port0`) which links to a device like `/dev/ttyUSB0`  This path remains consistent even after unplugging and replugging the device.

In the Proxmox web interface, navigate to the container's Resources, click Add, then Device Passthrough, and enter the full path such as `/dev/serial/by-id/usb-FTDI_FT230X_Basic_UART_D307ORET-if00-port0`  This method is considered clean and stable 

Alternatively, if you need more control or the persistent path is unavailable, edit the container's configuration file located at `/etc/pve/lxc/<container_id>.conf`. Use `lsusb` to find the bus and device numbers (e.g., 001, 003), then run `ls -al /dev/bus/usb/001/003` to get the major and minor numbers (e.g., 189, 130)  Add the following lines to the config file:

```
lxc.cgroup2.devices.allow: c 189:* rwm
lxc.mount.entry: /dev/ttyUSB0 dev/ttyUSB0 none bind,optional,create=file
```

Replace `189` with your device’s major number and `ttyUSB0` with the correct device name  The `rwm` flag grants read, write, and mknod permissions  After saving, restart the container.

If the device appears but has incorrect ownership (e.g., `nobody:nogroup`), fix it by changing the device’s owner and group on the host using the container’s user and group IDs. For example, if the container’s dialout group ID is 20, run `chown 100000:100020 /dev/ttyUSB0` on the host  This ensures the device is accessible within the container.

Finally, verify the device is visible inside the container by running `ls /dev` or `lsusb` after the container restarts 

## Elaborated
To ensure a USB device appears reliably in `/dev` within a Debian Trixie LXC container on Proxmox and survives reboots or replugging, follow these steps:

### 1. **Use Persistent Device Paths**
Instead of relying on transient paths like `/dev/ttyUSB0`, use stable symlinks from `/dev/serial/by-id/` or create custom UDEV rules.

- On the host, run:
  ```bash
  ls -l /dev/serial/by-id/
  ```
  This gives a persistent path like `usb-Silicon_Labs_CP210x-if00-port0` → `ttyUSB0`.

- In the container config (`/etc/pve/lxc/<ID>.conf`), add:
  ```
  lxc.mount.entry: /dev/serial/by-id/usb-Silicon_Labs_CP210x-if00-port0 dev/ttyUSB0 none bind,optional,create=file
  ```
  This ensures the device is consistently mapped even after disconnects.

### 2. **Grant Device Permissions**
Allow the container to access the device by its major number.

- Find the major number:
  ```bash
  ls -l /dev/ttyUSB0
  # Output: crw-rw---- 1 root dialout 188, 0 Apr  5 10:00 /dev/ttyUSB0
  ```
  Here, `188` is the major number.

- Add to the container config:
  ```
  lxc.cgroup2.devices.allow: c 188:* rwm
  ```

### 3. **Preserve Permissions Across Reboots**
If permissions reset after reboot, use systemd or tmpfiles.

- Create a tmpfile rule:
  ```bash
  echo 'z /dev/ttyUSB0 660 100000 100000' > /etc/tmpfiles.d/usb.conf
  ```
  Replace `100000` with your container’s UID/GID if unprivileged.

- Or use a systemd service:
  ```ini
  # /etc/systemd/system/usb_owner.service
  [Unit]
  Description=Set USB ownership
  [Service]
  Type=oneshot
  ExecStart=chown 100000:100000 /dev/ttyUSB0
  [Install]
  WantedBy=multi-user.target
  ```
  Enable with:
  ```bash
  systemctl daemon-reload
  systemctl enable usb_owner.service
  ```

### 4. **Optional: Create Custom UDEV Rules**
For full control, create a UDEV rule on the host.

- Example rule (`/etc/udev/rules.d/99-usb-serial.rules`):
  ```
  SUBSYSTEM=="tty", ATTRS{idVendor}=="10c4", ATTRS{idProduct}=="ea60", SYMLINK+="mydevice", GROUP="dialout", MODE="0660"
  ```
- Reload rules:
  ```bash
  udevadm control --reload && udevadm trigger
  ```

Then pass `/dev/mydevice` into the container.

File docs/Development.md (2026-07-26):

# Development Guide

This page is for developers working on mag-usb.
 
## Repository layout
- src/: C sources and headers
- tests/: Unit tests (CTest)
- install/: Deployment assets (e.g., udev rules)
- docs/: User and developer documentation
- assets/: Reference logs, notes, and images (keep large binaries here when necessary)

## Build matrix
- CMake 3.22+
- C11
- GCC or Clang
- Recommended warning flags are enabled by default: -Wall -Wextra -Wpedantic
- Optional: -DENABLE_WERROR=ON to treat warnings as errors (should be clean)

## Common targets
- mag-usb (main CLI)
- i2c-pololu-tests (unit tests for the Pololu adapter logic)
- mqtt-listener (MQTT testing tool)
- mqtt-command (MQTT remote command tool)

## Local builds
- Debug profile: faster iteration, symbols
- Release profile: optimized binary
- Dependencies: Requires OpenSSL development headers (`libssl-dev` on Debian/Ubuntu).

CLion profiles are preconfigured (cmake-build-debug/release). From CLI:
```
cmake -S . -B build -DCMAKE_BUILD_TYPE=Debug
cmake --build build --target mag-usb
```

## Running tests
```
cmake -S . -B build -DBUILD_TESTING=ON
cmake --build build --target i2c-pololu-tests
(cd build && ctest --output-on-failure)
```

## Coding patterns
- Keep internal helper functions static and out of public headers.
- Avoid global state where possible; prefer passing pList* explicitly.
- Be strict on error handling: check return codes of system calls and I/O.
- Use explicit (void)param casts to silence intentional unused-parameter warnings.
- Cast to const uint8_t* when interacting with byte APIs to avoid signedness warnings.

## Style and tools
- No enforced formatter; follow existing code style.
- You may use clang-format/clang-tidy locally; do not submit sweeping reformat PRs.
- Consider enabling -DENABLE_WERROR=ON locally to catch regressions early.

## Release process (suggested)
- Update CHANGES.txt or a future CHANGELOG.md.
- Tag versions using SemVer (suggest starting at v0.1.0 when ready).
- Build Debug and Release; run CTest in both configurations.

## Contributors
See [docs/Contributors.md](Contributors.md) for the list of individuals and AI assistants who have contributed to this project.

## Roadmap ideas (for discussion)
- Expand unit tests to cover error cases and edge conditions in i2c-pololu.c.
- Add a mock adapter for offline testing.
- Introduce a simple CI workflow to build and run tests on push/PR.
- Split device-specific docs and usage examples into separate pages.

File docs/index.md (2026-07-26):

# mag-usb Documentation

Welcome to the mag-usb documentation site. This project provides a USB-connected interface and tools for working with magnetometer sensors.

Use the navigation to the left or the links below to explore the documentation.

If you are building a fresh implementation, start with the Requirements page.

## Contents

```{toctree}
:caption: Contents
:maxdepth: 2

Getting-Started
Hardware-Setup
MacOS-Setup
Configuration
Data-Format
Orientation-and-Axes
Requirements
Troubleshooting
Limitations
Development
WebSocket-Options
Code-Review-and-Critique-2026-05-15-by-gemini-3-flash-preview
Code-Review-2026-06-02-by-claude
```

## Local preview

You can build and preview this site locally with MkDocs. First, create a virtual environment and install the docs dependencies:

```bash
python3 -m venv .venv
. .venv/bin/activate
pip install -r docs/requirements.txt
```

Then serve the site locally:

```bash
mkdocs serve
```

Open the URL printed by MkDocs (typically http://127.0.0.1:8000/) to preview.

## Read the Docs

This repository is configured for Read the Docs using `.readthedocs.yaml` and `docs/conf.py`.

To publish the site on Read the Docs:

1. Push these files to your default branch.
2. Log in to https://readthedocs.org/ and import the project by pointing it at your repository.
3. In the RTD project settings, ensure the configuration file path is `.readthedocs.yaml`.
4. Trigger a build. RTD will install `docs/requirements.txt` and build the Sphinx site.
5. Once built, add the RTD URL to your repository README.

If your repository is hosted publicly (e.g., GitHub/GitLab), update `repo_url` in `mkdocs.yml` to enable "Edit this page" links.

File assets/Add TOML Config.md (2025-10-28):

## Me:
I want to add the ability to read and write configuration values to a TOML file named 'config.toml' that allows this program to persist configurations between startups.  Parameters received from the command line should override these settings, but should not persist between runs. I would prefer to avoid using an external library if possible, but a header-only library is OK.

## AI Chat:
I'll help you add TOML configuration support to your project. Since you prefer to avoid external libraries but are open to header-only solutions, I recommend using **tomlc99** or **toml++**, but given your project is in C, the best lightweight option is **toml.c** by cktan.

However, since you want to avoid dependencies if possible, let me provide a **simple custom TOML parser** that handles basic key-value pairs suitable for your configuration needs. This will be header-only and tailored to your `pList` structure.

Here's my solution:

## Step 1: Create a simple TOML configuration handler

```c++
//=========================================================================
// config_toml.h
//
// Simple TOML configuration file reader/writer for mag-usb
// Handles basic key=value pairs for configuration persistence
//
// License:     GPL 3.0
//=========================================================================
#ifndef CONFIG_TOML_H
#define CONFIG_TOML_H

#include <stdio.h>
#include <stdlib.h>
#include <string.h>
#include <errno.h>

#define CONFIG_LINE_MAX 256
#define CONFIG_KEY_MAX 64
#define CONFIG_VALUE_MAX 192

// Configuration structure matching pList parameters
typedef struct {
    // I2C Configuration
    int i2cBusNumber;
    int magAddr;
    int localTempAddr;
    int remoteTempAddr;
    
    // Magnetometer Configuration
    int cc_x;
    int cc_y;
    int cc_z;
    int x_gain;
    int y_gain;
    int z_gain;
    
    // Timing and Sampling
    int TMRCRate;
    int CMMSampleRate;
    int samplingMode;
    int NOSRegValue;
    int DRDYdelay;
    
    // Options
    int scanI2CBUS;
    int doBistMask;
    int readBackCCRegs;
    int tsMilliseconds;
    int usePipes;
    
    // Paths
    char portpath[CONFIG_VALUE_MAX];
    char pipeInPath[CONFIG_VALUE_MAX];
    char pipeOutPath[CONFIG_VALUE_MAX];
} Config;

// Initialize config with default values
static void config_init_defaults(Config *cfg) {
    if (!cfg) return;
    
    // I2C defaults
    cfg->i2cBusNumber = 1;
    cfg->magAddr = 0x20;
    cfg->localTempAddr = 0x18;
    cfg->remoteTempAddr = 0x19;
    
    // Magnetometer defaults
    cfg->cc_x = 200;
    cfg->cc_y = 200;
    cfg->cc_z = 200;
    cfg->x_gain = 1;
    cfg->y_gain = 1;
    cfg->z_gain = 1;
    
    // Timing defaults
    cfg->TMRCRate = 0;
    cfg->CMMSampleRate = 1;
    cfg->samplingMode = 0;
    cfg->NOSRegValue = 0;
    cfg->DRDYdelay = 100;
    
    // Options defaults
    cfg->scanI2CBUS = 0;
    cfg->doBistMask = 0;
    cfg->readBackCCRegs = 0;
    cfg->tsMilliseconds = 0;
    cfg->usePipes = 0;
    
    // Paths defaults
    strncpy(cfg->portpath, "/dev/i2c-1", CONFIG_VALUE_MAX - 1);
    cfg->portpath[CONFIG_VALUE_MAX - 1] = '\0';
    cfg->pipeInPath[0] = '\0';
    cfg->pipeOutPath[0] = '\0';
}

// Trim whitespace from string
static char* trim_whitespace(char *str) {
    char *end;
    
    // Trim leading space
    while (*str == ' ' || *str == '\t') str++;
    
    if (*str == 0) return str;
    
    // Trim trailing space
    end = str + strlen(str) - 1;
    while (end > str && (*end == ' ' || *end == '\t' || *end == '\n' || *end == '\r')) {
        end--;
    }
    *(end + 1) = '\0';
    
    return str;
}

// Remove quotes from string value
static void remove_quotes(char *str) {
    size_t len = strlen(str);
    if (len >= 2 && str[0] == '"' && str[len-1] == '"') {
        memmove(str, str + 1, len - 2);
        str[len - 2] = '\0';
    }
}

// Parse a single line and update config
static int parse_config_line(Config *cfg, char *line) {
    char key[CONFIG_KEY_MAX];
    char value[CONFIG_VALUE_MAX];
    char *eq_pos;
    char *trimmed;
    
    // Skip comments and empty lines
    trimmed = trim_whitespace(line);
    if (trimmed[0] == '#' || trimmed[0] == '\0' || trimmed[0] == '[') {
        return 0;
    }
    
    // Find '=' separator
    eq_pos = strchr(trimmed, '=');
    if (!eq_pos) return 0;
    
    // Extract key
    *eq_pos = '\0';
    strncpy(key, trim_whitespace(trimmed), CONFIG_KEY_MAX - 1);
    key[CONFIG_KEY_MAX - 1] = '\0';
    
    // Extract value
    strncpy(value, trim_whitespace(eq_pos + 1), CONFIG_VALUE_MAX - 1);
    value[CONFIG_VALUE_MAX - 1] = '\0';
    remove_quotes(value);
    
    // Match key and set value
    if (strcmp(key, "i2cBusNumber") == 0) {
        cfg->i2cBusNumber = atoi(value);
    } else if (strcmp(key, "magAddr") == 0) {
        cfg->magAddr = (int)strtol(value, NULL, 0);
    } else if (strcmp(key, "localTempAddr") == 0) {
        cfg->localTempAddr = (int)strtol(value, NULL, 0);
    } else if (strcmp(key, "remoteTempAddr") == 0) {
        cfg->remoteTempAddr = (int)strtol(value, NULL, 0);
    } else if (strcmp(key, "cc_x") == 0) {
        cfg->cc_x = atoi(value);
    } else if (strcmp(key, "cc_y") == 0) {
        cfg->cc_y = atoi(value);
    } else if (strcmp(key, "cc_z") == 0) {
        cfg->cc_z = atoi(value);
    } else if (strcmp(key, "x_gain") == 0) {
        cfg->x_gain = atoi(value);
    } else if (strcmp(key, "y_gain") == 0) {
        cfg->y_gain = atoi(value);
    } else if (strcmp(key, "z_gain") == 0) {
        cfg->z_gain = atoi(value);
    } else if (strcmp(key, "TMRCRate") == 0) {
        cfg->TMRCRate = atoi(value);
    } else if (strcmp(key, "CMMSampleRate") == 0) {
        cfg->CMMSampleRate = atoi(value);
    } else if (strcmp(key, "samplingMode") == 0) {
        cfg->samplingMode = atoi(value);
    } else if (strcmp(key, "NOSRegValue") == 0) {
        cfg->NOSRegValue = atoi(value);
    } else if (strcmp(key, "DRDYdelay") == 0) {
        cfg->DRDYdelay = atoi(value);
    } else if (strcmp(key, "scanI2CBUS") == 0) {
        cfg->scanI2CBUS = atoi(value);
    } else if (strcmp(key, "doBistMask") == 0) {
        cfg->doBistMask = atoi(value);
    } else if (strcmp(key, "readBackCCRegs") == 0) {
        cfg->readBackCCRegs = atoi(value);
    } else if (strcmp(key, "tsMilliseconds") == 0) {
        cfg->tsMilliseconds = atoi(value);
    } else if (strcmp(key, "usePipes") == 0) {
        cfg->usePipes = atoi(value);
    } else if (strcmp(key, "portpath") == 0) {
        strncpy(cfg->portpath, value, CONFIG_VALUE_MAX - 1);
        cfg->portpath[CONFIG_VALUE_MAX - 1] = '\0';
    } else if (strcmp(key, "pipeInPath") == 0) {
        strncpy(cfg->pipeInPath, value, CONFIG_VALUE_MAX - 1);
        cfg->pipeInPath[CONFIG_VALUE_MAX - 1] = '\0';
    } else if (strcmp(key, "pipeOutPath") == 0) {
        strncpy(cfg->pipeOutPath, value, CONFIG_VALUE_MAX - 1);
        cfg->pipeOutPath[CONFIG_VALUE_MAX - 1] = '\0';
    }
    
    return 0;
}

// Read configuration from TOML file
static int config_read(const char *filename, Config *cfg) {
    FILE *fp;
    char line[CONFIG_LINE_MAX];
    
    if (!filename || !cfg) return -1;
    
    fp = fopen(filename, "r");
    if (!fp) {
        if (errno == ENOENT) {
            // File doesn't exist, use defaults
            fprintf(OUTPUT_ERROR, "Config file '%s' not found, using defaults\n", filename);
            return 0;
        }
        perror("Error opening config file");
        return -1;
    }
    
    while (fgets(line, sizeof(line), fp)) {
        parse_config_line(cfg, line);
    }
    
    fclose(fp);
    return 0;
}

// Write configuration to TOML file
static int config_write(const char *filename, const Config *cfg) {
    FILE *fp;
    
    if (!filename || !cfg) return -1;
    
    fp = fopen(filename, "w");
    if (!fp) {
        perror("Error creating config file");
        return -1;
    }
    
    fprintf(fp, "# mag-usb Configuration File\n");
    fprintf(fp, "# Generated automatically\n\n");
    
    fprintf(fp, "[i2c]\n");
    fprintf(fp, "i2cBusNumber = %d\n", cfg->i2cBusNumber);
    fprintf(fp, "magAddr = 0x%02X\n", cfg->magAddr);
    fprintf(fp, "localTempAddr = 0x%02X\n", cfg->localTempAddr);
    fprintf(fp, "remoteTempAddr = 0x%02X\n", cfg->remoteTempAddr);
    fprintf(fp, "portpath = \"%s\"\n\n", cfg->portpath);
    
    fprintf(fp, "[magnetometer]\n");
    fprintf(fp, "cc_x = %d\n", cfg->cc_x);
    fprintf(fp, "cc_y = %d\n", cfg->cc_y);
    fprintf(fp, "cc_z = %d\n", cfg->cc_z);
    fprintf(fp, "x_gain = %d\n", cfg->x_gain);
    fprintf(fp, "y_gain = %d\n", cfg->y_gain);
    fprintf(fp, "z_gain = %d\n", cfg->z_gain);
    fprintf(fp, "TMRCRate = %d\n", cfg->TMRCRate);
    fprintf(fp, "CMMSampleRate = %d\n", cfg->CMMSampleRate);
    fprintf(fp, "NOSRegValue = %d\n\n", cfg->NOSRegValue);
    
    fprintf(fp, "[timing]\n");
    fprintf(fp, "samplingMode = %d\n", cfg->samplingMode);
    fprintf(fp, "DRDYdelay = %d\n", cfg->DRDYdelay);
    fprintf(fp, "tsMilliseconds = %d\n\n", cfg->tsMilliseconds);
    
    fprintf(fp, "[options]\n");
    fprintf(fp, "scanI2CBUS = %d\n", cfg->scanI2CBUS);
    fprintf(fp, "doBistMask = %d\n", cfg->doBistMask);
    fprintf(fp, "readBackCCRegs = %d\n", cfg->readBackCCRegs);
    fprintf(fp, "usePipes = %d\n", cfg->usePipes);
    
    if (cfg->pipeInPath[0] != '\0') {
        fprintf(fp, "pipeInPath = \"%s\"\n", cfg->pipeInPath);
    }
    if (cfg->pipeOutPath[0] != '\0') {
        fprintf(fp, "pipeOutPath = \"%s\"\n", cfg->pipeOutPath);
    }
    
    fclose(fp);
    return 0;
}

// Apply configuration to pList structure
static void config_apply_to_plist(const Config *cfg, void *plist_ptr) {
    // Forward declaration - you'll implement this in your main.c
    // to copy values from Config to pList
    extern void apply_config_to_plist(const Config *cfg, void *p);
    apply_config_to_plist(cfg, plist_ptr);
}

#endif // CONFIG_TOML_H
```

## Step 2: Update main.h to include config support

```c++
// ... existing code ...
#include <sys/time.h>
#include "MCP9808.h"
#include "config_toml.h"
//#include "rm3100.h"

// ... existing code ...
```

## Step 3: Add helper functions to your main.c

You'll need to add these functions to your main.c file:

```c++
// Apply configuration from Config struct to pList
void apply_config_to_plist(const Config *cfg, void *plist_ptr) {
    pList *p = (pList *)plist_ptr;
    
    if (!cfg || !p) return;
    
    // Copy values from config to pList
#if(!USE_POLOLU)
    p->i2cBusNumber = cfg->i2cBusNumber;
#endif
    p->magAddr = cfg->magAddr;
    p->localTempAddr = cfg->localTempAddr;
    p->remoteTempAddr = cfg->remoteTempAddr;
    
    p->cc_x = cfg->cc_x;
    p->cc_y = cfg->cc_y;
    p->cc_z = cfg->cc_z;
    p->x_gain = cfg->x_gain;
    p->y_gain = cfg->y_gain;
    p->z_gain = cfg->z_gain;
    
    p->TMRCRate = cfg->TMRCRate;
    p->CMMSampleRate = cfg->CMMSampleRate;
    p->samplingMode = cfg->samplingMode;
    p->NOSRegValue = cfg->NOSRegValue;
    p->DRDYdelay = cfg->DRDYdelay;
    
    p->scanI2CBUS = cfg->scanI2CBUS;
    p->doBistMask = cfg->doBistMask;
    p->readBackCCRegs = cfg->readBackCCRegs;
    p->tsMilliseconds = cfg->tsMilliseconds;
    p->usePipes = cfg->usePipes;
    
    // Only copy paths if not already set
    if (p->portpath == NULL && cfg->portpath[0] != '\0') {
        p->portpath = strdup(cfg->portpath);
    }
    if (p->pipeInPath == NULL && cfg->pipeInPath[0] != '\0') {
        p->pipeInPath = strdup(cfg->pipeInPath);
    }
    if (p->pipeOutPath == NULL && cfg->pipeOutPath[0] != '\0') {
        p->pipeOutPath = strdup(cfg->pipeOutPath);
    }
}

// Load configuration, with command-line overrides
int load_configuration(pList *p, const char *config_file) {
    Config cfg;
    
    // Initialize with defaults
    config_init_defaults(&cfg);
    
    // Read from file (if it exists)
    if (config_read(config_file, &cfg) < 0) {
        fprintf(OUTPUT_ERROR, "Warning: Could not read config file, using defaults\n");
    }
    
    // Apply to pList (command line args will override later)
    apply_config_to_plist(&cfg, p);
    
    return 0;
}

// Save current configuration
int save_configuration(const pList *p, const char *config_file) {
    Config cfg;
    
    // Initialize to avoid garbage
    config_init_defaults(&cfg);
    
    // Copy current values from pList
#if(!USE_POLOLU)
    cfg.i2cBusNumber = p->i2cBusNumber;
#endif
    cfg.magAddr = p->magAddr;
    cfg.localTempAddr = p->localTempAddr;
    cfg.remoteTempAddr = p->remoteTempAddr;
    
    cfg.cc_x = p->cc_x;
    cfg.cc_y = p->cc_y;
    cfg.cc_z = p->cc_z;
    cfg.x_gain = p->x_gain;
    cfg.y_gain = p->y_gain;
    cfg.z_gain = p->z_gain;
    
    cfg.TMRCRate = p->TMRCRate;
    cfg.CMMSampleRate = p->CMMSampleRate;
    cfg.samplingMode = p->samplingMode;
    cfg.NOSRegValue = p->NOSRegValue;
    cfg.DRDYdelay = p->DRDYdelay;
    
    cfg.scanI2CBUS = p->scanI2CBUS;
    cfg.doBistMask = p->doBistMask;
    cfg.readBackCCRegs = p->readBackCCRegs;
    cfg.tsMilliseconds = p->tsMilliseconds;
    cfg.usePipes = p->usePipes;
    
    if (p->portpath) {
        strncpy(cfg.portpath, p->portpath, CONFIG_VALUE_MAX - 1);
    }
    if (p->pipeInPath) {
        strncpy(cfg.pipeInPath, p->pipeInPath, CONFIG_VALUE_MAX - 1);
    }
    if (p->pipeOutPath) {
        strncpy(cfg.pipeOutPath, p->pipeOutPath, CONFIG_VALUE_MAX - 1);
    }
    
    return config_write(config_file, &cfg);
}
```

## Step 4: Integrate into your main() function

In your `main()` function, call `load_configuration()` before parsing command-line arguments:

```c++
int main(int argc, char** argv) {
    pList params;
    const char *config_file = "config.toml";
    
    // Initialize pList with zeros
    memset(&params, 0, sizeof(pList));
    
    // Load configuration from file (if exists)
    load_configuration(&params, config_file);
    
    // Parse command-line arguments (these will override config file)
    // ... your existing argument parsing code ...
    
    // Rest of your main function
    // ... existing code ...
}
```

## Usage Example

Create a `config.toml` file:

```toml
# mag-usb Configuration File

[i2c]
i2cBusNumber = 1
magAddr = 0x20
localTempAddr = 0x18
remoteTempAddr = 0x19
portpath = "/dev/i2c-1"

[magnetometer]
cc_x = 200
cc_y = 200
cc_z = 200
x_gain = 1
y_gain = 1
z_gain = 1
TMRCRate = 0
CMMSampleRate = 1
NOSRegValue = 0

[timing]
samplingMode = 0
DRDYdelay = 100
tsMilliseconds = 0

[options]
scanI2CBUS = 0
doBistMask = 0
readBackCCRegs = 0
usePipes = 0
```

This solution:
- ✅ Uses no external libraries (fully self-contained)
- ✅ Is header-only with implementation functions
- ✅ Reads TOML configuration on startup
- ✅ Allows command-line arguments to override settings
- ✅ Command-line overrides don't persist between runs
- ✅ Provides a simple API to save configurations when needed

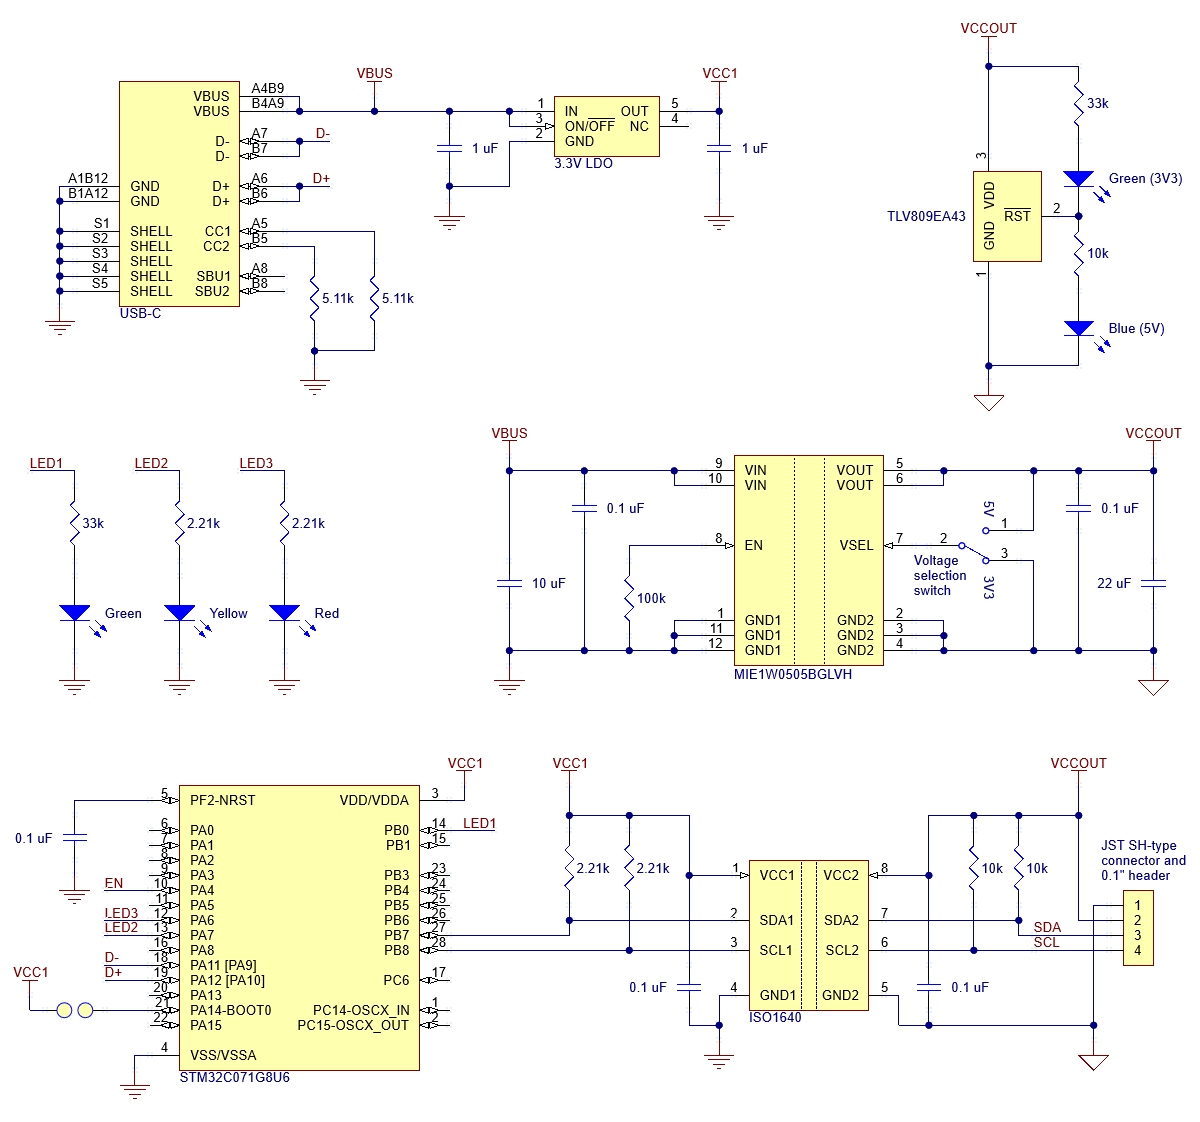
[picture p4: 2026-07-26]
assets/Pololu Schematic - 0J13223.1200.png

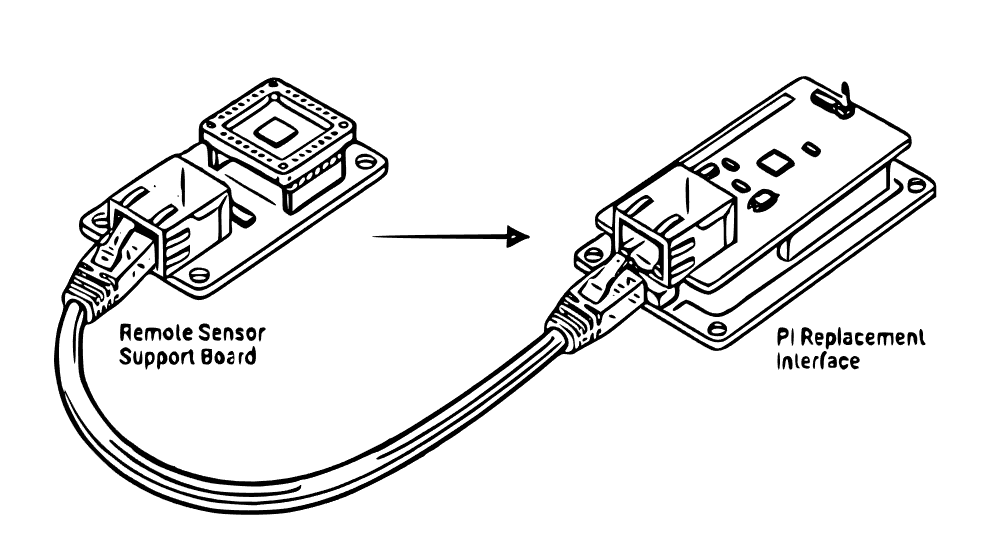
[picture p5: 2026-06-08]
assets/Pi Eliminator-image-3-Vectorized.png

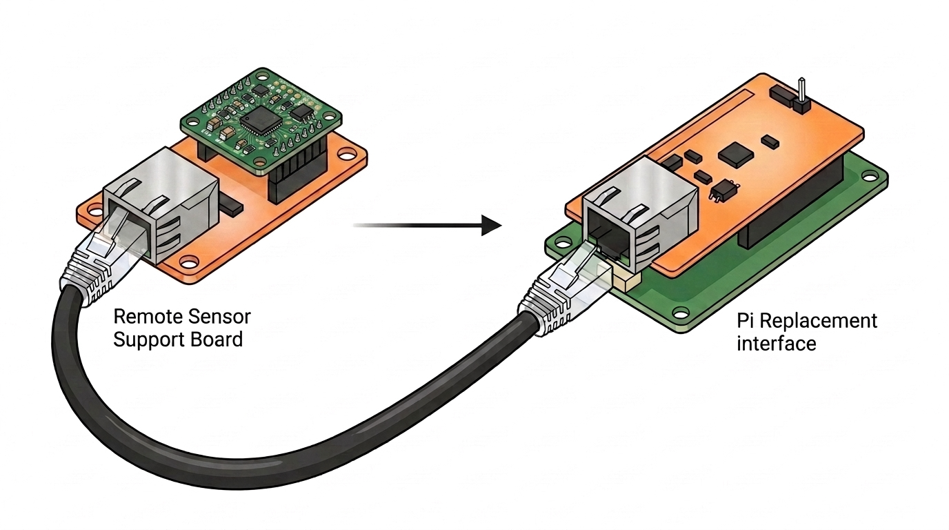
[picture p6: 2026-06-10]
assets/Pi Eliminator -image-4.png

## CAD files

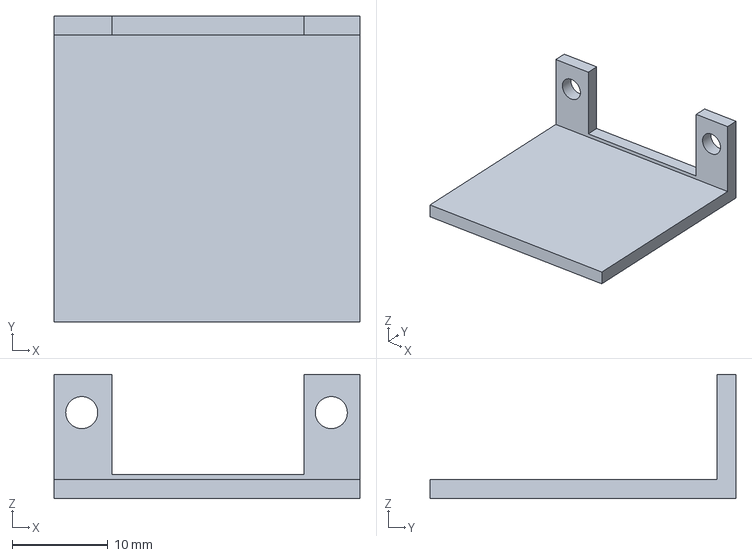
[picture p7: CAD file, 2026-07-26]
assets/HDMI_plug_block6.3mf
32.0 x 32.0 x 13.0 mm

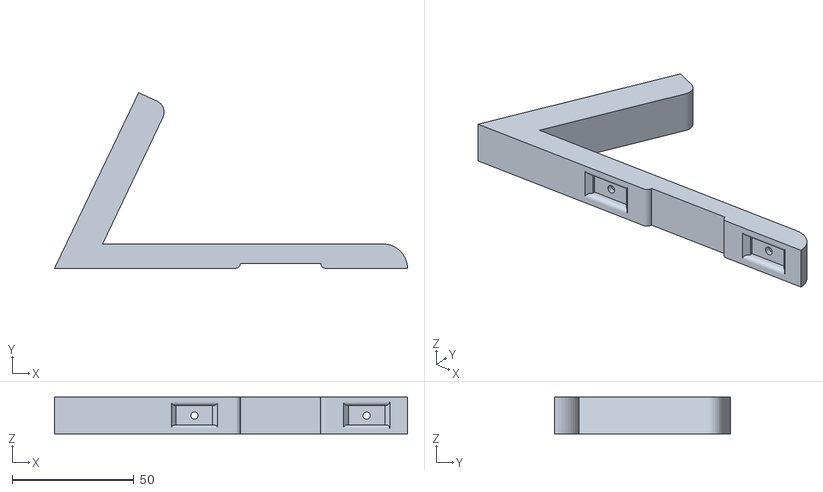
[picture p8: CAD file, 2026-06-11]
assets/Pi Touch Display 2 Stand/Pi Touch Display 2 Stand.stl
145.0 x 72.2 x 15.0

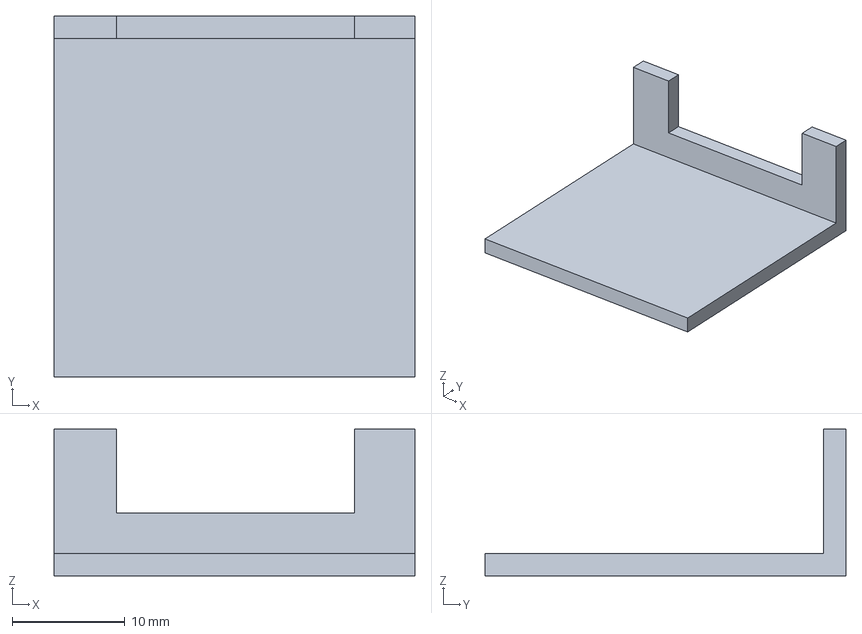
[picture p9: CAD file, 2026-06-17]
assets/HDMI_plug_block4.3mf
32.0 x 32.0 x 13.0 mm

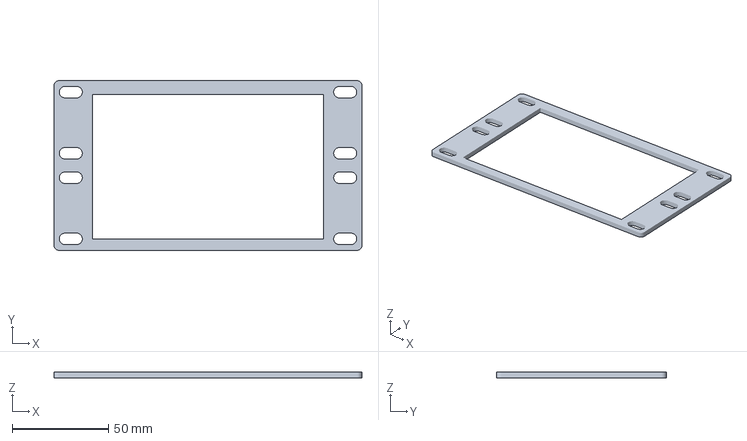
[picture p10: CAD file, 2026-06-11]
assets/Pi Touch Display 3 Stand/PiDisplay3-Small-panel.3mf
159.9 x 88.1 x 3.00 mm

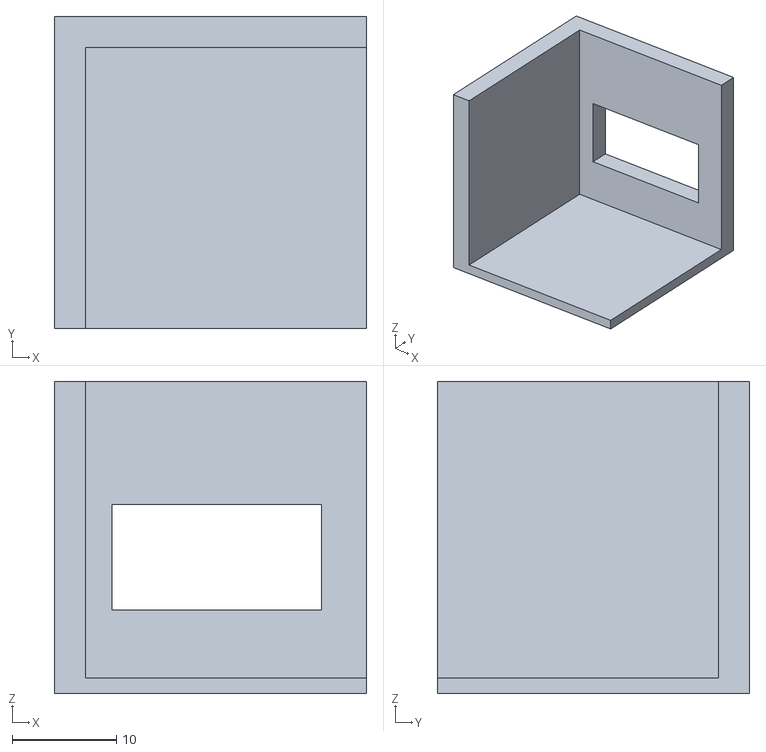
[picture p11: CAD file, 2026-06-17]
assets/HDMI_plug_block.stl
30.0 x 30.0 x 30.0

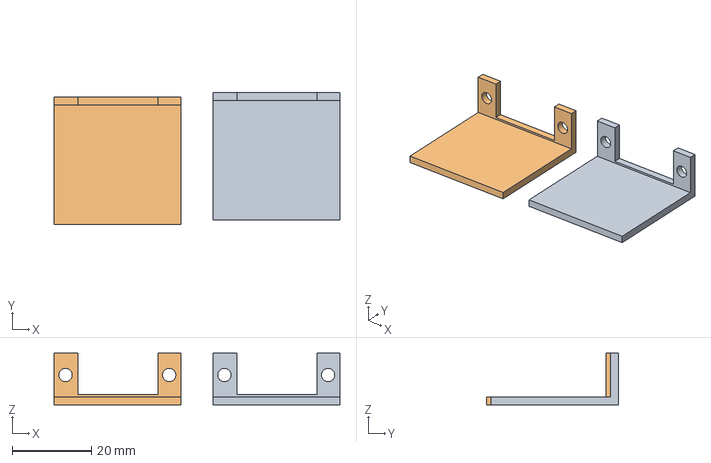
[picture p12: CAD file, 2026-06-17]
assets/HDMI_plug_block6_dual.3mf
72.0 x 33.2 x 13.0 mm
HDMI_plug_block6 x 2

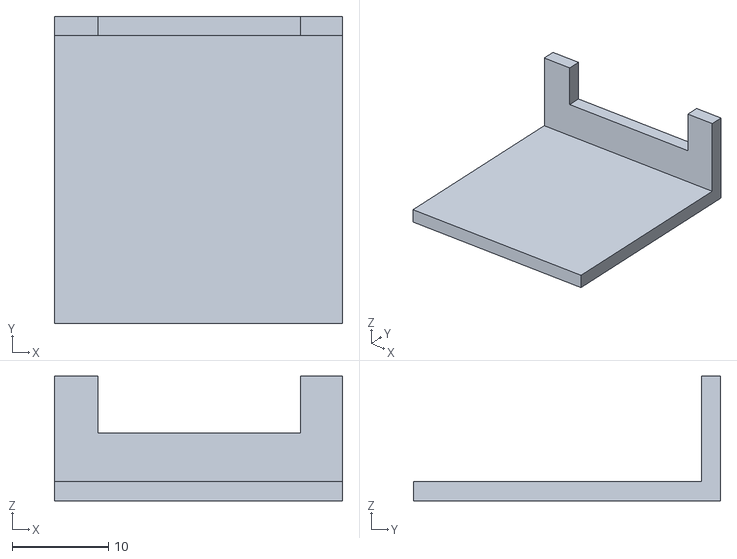
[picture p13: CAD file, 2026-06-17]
assets/HDMI_plug_block2.stl
30.0 x 32.0 x 13.0

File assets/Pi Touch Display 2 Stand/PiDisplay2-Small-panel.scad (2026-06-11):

// Simple rack panel for Pi Display 2 (small)
//
// (c) 2026 David M. Witten II
//===================================================================
// Constant Parameters
use <rack_plate.scad>
in2mm               = 25.41;  // mm / in

plate_length        = 6.3;    // inches 123 mm
plate_width         = 160.0;  // mm
plate_thickness     = 3.0;    // mm

left_notch_width    = 4.0;    // mm
left_notch_ht       = 50.0;   // mm

mnt_hole_width      = 7.5;    // mm
mnt_hole_len        = 11.0;   // mm

//===================================================================
// Modifiable Parameters


//===================================================================
// Main()
module cutout()
{
    display_cutout = cube([127, 73, 16]);
}

//===================================================================
// main()
module main()
{
    difference()
    {
        rack_plate(u_count = 2, thickness = plate_thickness, width_inches = plate_length);
        translate([(140 - 123), 6, -8])
        {
            cube([126, 75, 16]);
            //#cutout();
        }
        translate([(140 - 127), (left_notch_ht/3)+2 , -8])
        {
            cube([left_notch_width+ 0.5, left_notch_ht, 16]);
            //#cutout();
        }
    }
}

main();

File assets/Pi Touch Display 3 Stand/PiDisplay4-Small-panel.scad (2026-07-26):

// Simple rack panel for Pi Display 2 (small)
//
// (c) 2026 David M. Witten II
//===================================================================
// Constant Parameters
use <rack_plate.scad>
in2mm               = 25.41;  // mm / in

plate_length        = 16.0;   // mm
plate_width         = 160.0;  // mm
plate_thickness     = 2.0;    // mm

mnt_hole_width      = 7.5;    // mm
mnt_hole_len        = 11.0;   // mm

//===================================================================
// Modifiable Parameters


//===================================================================
// Main()
module cutout()
{
    display_cutout = cube([120, 75, 16]);
}

//===================================================================
// main()
module main()
{
    difference()
    {
        rack_plate(u_count = 1, thickness = plate_thickness, width_inches = (plate_length/(in2mm/10)));
        translate([(140 - 120.75), 5.5, -8])
        {
            cube([121.5, 75.75, 16]);
        }
    }
}

main();

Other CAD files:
assets/HDMI_plug_block5.3mf
assets/HDMI_plug_block3.stl
assets/Pi Touch Display 3 Stand/PiDisplay3-Small-panel.scad
assets/HDMI_plug_block4.scad
assets/HDMI_plug_block6.scad
assets/Pi Touch Display 2 Stand/rack_plate.scad
assets/Pi Touch Display 3 Stand/PiDisplay3-Small-panel.stl
assets/Pi Touch Display 3 Stand/rack_plate.scad

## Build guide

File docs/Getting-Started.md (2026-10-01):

# Getting Started

This guide helps you install, build, and run mag-usb on a typical Linux system.

## Prerequisites
- Linux host with USB 2.0 support
- CMake 3.22+
- A C compiler (GCC or Clang)
- Optional: Microsoft VS Code, VSCodium, or JetBrains CLion for an IDE workflow
- Pololu Isolated USB-to-I²C Adapter (products 5396 or 5397)
- RM3100-based magnetometer board

## Hardware connection
1. Connect the Pololu USB-to-I²C adapter to your host via USB.
2. Wire SDA/SCL/GND (and 5V if required) between the adapter and the sensor board.
3. On Linux, the adapter typically appears as /dev/ttyACMn. Installing
   `install/99-PololuI2C.rules` adds a `/dev/ttyMAG0` symlink that
   resolves to whichever ACM device the adapter enumerated as — this is
   the path the program uses by default.

For details and udev rules to stabilize the device path, see docs/Hardware-Setup.md.

## Build
You can build using CLion or plain CMake.

CLion:
- Open the project folder.
- Select the Debug or Release profile.
- Build the target: mag-usb

Command line (Release example):
```
cmake -S . -B build -DCMAKE_BUILD_TYPE=Release
cmake --build build --target mag-usb
```

## Quick run
```
./build/mag-usb -Q                    # default device: /dev/ttyMAG0
./build/mag-usb -O /dev/ttyACM0 -Q    # explicit override
```
Flags:
- -O sets the Pololu device path.
- -Q checks adapter presence/availability.

Print current settings (and exit):
```
./build/mag-usb -P
```
The program searches for `config.toml` in `/etc/mag-usb/` first, then in the local directory. If neither is found, internal defaults are used.

## Named Pipes (Optional)
To enable named pipe output for local monitoring:
```
./build/mag-usb -u
```
You can specify custom pipe paths with `-i` and `-o`. Defaults are in `/var/run/`.

## MQTT Publication (New)
MQTT support is included by default but must be enabled in `config.toml`. It publishes sensor data at 1Hz and supports secure `mqtts://` connections.

To use MQTT:
1. Ensure `libssl-dev` is installed on your system.
2. The broker's TLS certificate is verified. `test.mosquitto.org` uses its own CA, so download it:
```bash
sudo curl -o /etc/mag-usb/mosquitto.org.crt https://test.mosquitto.org/ssl/mosquitto.org.crt
```
3. Edit `config.toml` (or `/etc/mag-usb/config.toml`) and add:
```toml
[mqtt]
enable = true
broker_address = "test.mosquitto.org"
broker_port = 8883
topic = "mag-usb/your-unique-topic"
use_tls = true
ca_file = "/etc/mag-usb/mosquitto.org.crt"
```
For a broker with a certificate from a public CA, leave `ca_file` out.
4. Run `mag-usb`:
```
./build/mag-usb
```

You can use the built-in testing tools to verify the connection:
```bash
# Listen for data
./build/mqtt-listener test.mosquitto.org 8883 mag-usb/your-unique-topic

# Request configuration remotely
./build/mqtt-command test.mosquitto.org 8883 mag-usb/your-unique-topic/command get_config
```

## WebSocket Output (Optional)
Enable WebSocket support at build time:
```
cmake -S . -B build -DENABLE_WEBSOCKET=ON
cmake --build build --target mag-usb
```
Then enable it at runtime:
```
./build/mag-usb -W -w 8765 -a 0.0.0.0
```
Or set the `[websocket]` section in `config.toml`.

For manual testing, build and run the `ws-client` tool:
```
cmake --build build --target ws-client
./build/ws-client 127.0.0.1 8765 /
```

Run with help:
```
./mag-usb -h
```

## Tests (optional)
Enable and run unit tests:
```
cmake -S . -B build -DBUILD_TESTING=ON
cmake --build build --target i2c-pololu-tests
(cd build && ctest --output-on-failure)
```

## Next steps
- Review README.md (command-line help section) and docs/Configuration.md for available flags and configuration keys.
- If you use the adapter regularly, consider installing the provided udev rule (install/99-PololuI2C.rules) to get stable permissions and device naming.

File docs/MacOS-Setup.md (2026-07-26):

# macOS Setup

This guide helps you install, build, and run mag-usb on a macOS computer.

## Prerequisites
- macOS host with USB 2.0 support
- Docker Desktop
- socat (install with Homebrew: `brew install socat`)
- Optional: Microsoft VS Code, VSCodium, or JetBrains CLion for an IDE workflow
- Pololu Isolated USB-to-I²C Adapter (products 5396 or 5397)
- RM3100-based magnetometer board

## Hardware connection
1. Connect the Pololu USB-to-I²C adapter to your host via USB.
2. Wire SDA/SCL/GND (and 5V if required) between the adapter and the sensor board.
3. Verify the adapter name in macOS by running `ls -l /dev/cu.*` before and after
   plugging in the adapter. On macOS, the adapter typically appears as
   /dev/cu.usbmodem14#01.

## Adapter Communication
After installing socat, run the following command in a separate terminal, substituting
`<DEVICE>` for the name of the adapter as verified during hardware setup:

```bash
socat -d -d TCP-LISTEN:1234,reuseaddr,fork FILE:<DEVICE>,raw,echo=0
```

You should see a similar output:

```
2026/06/04 14:43:09 socat[69640] N listening on LEN=16 AF=2 0.0.0.0:<PORT>
```

Example usage with device /dev/cu.usbmodem14101:

```bash
socat -d -d TCP-LISTEN:1234,reuseaddr,fork FILE:/dev/cu.usbmodem14101,raw,echo=0
```

## Deploying mag-usb
Open Docker Desktop to ensure the Docker engine is running. In another terminal,
navigate to the project directory and execute the following command:

```docker
docker compose up
```

This will create a Docker container with mag-usb already built. Upon launching the
container, the green LED on your Pololu adapter should blink once along with the
following output being displayed in your terminal:

```
(1) Starting virtual TTY bridge...
(2) Waiting for virtual device...
READY!
   To edit config: nano /etc/mag-usb/config.toml
   To run mag-usb: ./mag-usb
```

Press d inside this terminal to detach the terminal from the container.

The terminal running socat should display an output similar to the example below:

```
2026/06/04 21:40:18 socat[40636] N accepting connection from LEN=16 AF=2 127.0.0.1:52866 on LEN=16 AF=2 127.0.0.1:1234
2026/06/04 21:40:18 socat[40636] N forked off child process 49661
2026/06/04 21:40:18 socat[40636] N listening on LEN=16 AF=2 0.0.0.0:1234
2026/06/04 21:40:18 socat[49661] N opening character device "/dev/cu.usbmodem14101" for reading and writing
2026/06/04 21:40:18 socat[49661] N starting data transfer loop with FDs [6,6] and [5,5]
```

Refer to the [troubleshooting](#troubleshooting) section at the end of this page if the output in either
terminal is different.

### Using WebSockets
For WebSocket broadcasting, the container broadcasts on and exposes port 8765. To make mag-usb broadcast over WebSockets, enter the container and edit the config.toml in nano.

```bash
docker compose exec host bash
nano /etc/mag-usb/config.toml
```

Then, under the [websocket] section, change the value for enable from "false" to "true":

```toml
[websocket]
# Enable WebSocket output server.
enable = true
# Bind address and port for WebSocket clients.
bind_address = "0.0.0.0"
port = 8765
```

Press ctrl+x to save and exit. Run mag-usb with `./mag-usb &`. You can `exit` the container once mag-usb is up and running.

## Troubleshooting

### Refused Connection
If during the execution of the container you see a similar output:

```
(1) Starting virtual TTY bridge...
(2) Waiting for virtual device...
2026/06/05 00:25:33 socat[7] E connect(7, AF=2 192.168.65.254:1234, 16): Connection refused
```

Detach the container from the terminal, then run `docker compose down` to kill it.

Check the adapter to make sure it is properly connected to your computer by unplugging and plugging it back in.

Verify that the device name is correct by running `ls -l /dev/cu.*` after unplugging
and plugging the adapter into your computer.

Check socat to verify that it is running and what port the device is listening to. The adapter must listen on port 1234:

```bash
socat -d -d TCP-LISTEN:1234,reuseaddr,fork FILE:<DEVICE>,raw,echo=0
```

### Device Unavailable
If upon executing mag-usb you see this error:

```
I2C adapter device '/dev/ttyACM0' not available (error -2). Exiting...
```

This error is a result of socat exiting or the physical device being disconnected. The
container must be exited as it cannot reconnect to the adapter. Check the physical
adapter to make sure it is plugged in and restart socat.

If the device in the error is anything other than /dev/ttyACM0, check your config.toml
file for this line under `[i2c]` to make sure it matches:

```toml
portpath = "/dev/ttyACM0"
```

The container only reads from /dev/ttyACM0. Any other device will cause mag-usb to exit.

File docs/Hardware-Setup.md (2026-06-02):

# Hardware Setup

This guide helps you connect the Pololu USB-to-I²C adapter to the RM3100-based sensor and prepare your Linux system.

## Hardware
- Pololu Isolated USB-to-I²C Adapter:
  - 5397 (with isolated power output)
- RM3100 magnetometer board (e.g., TAPR/TangerineSDR magnetometer)
- Appropriate wiring for SDA, SCL, GND, and optional +5V

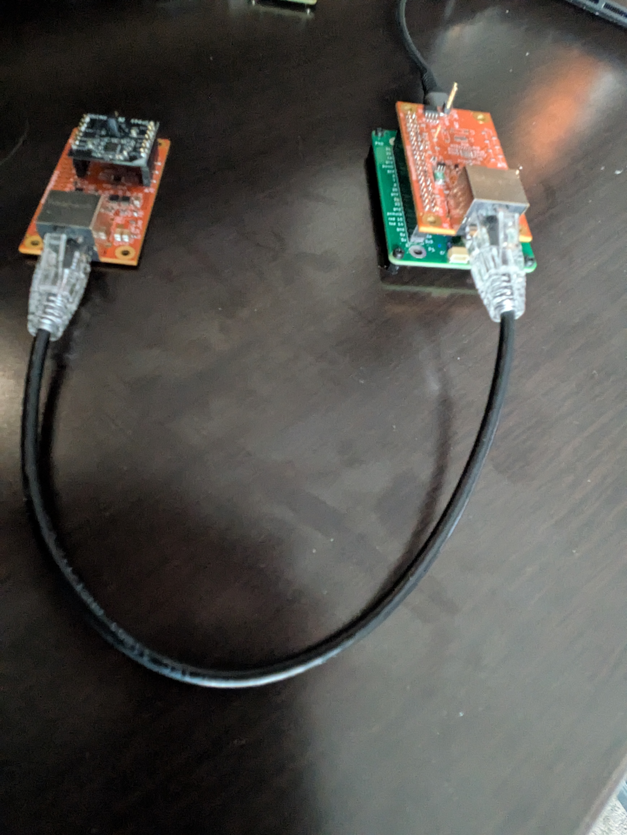
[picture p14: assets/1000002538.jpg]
Pololu Adapter and Sensor Setup

*Fig. 1: Pololu USB-to-I²C adapter connected to the RM3100 magnetometer sensor.*

## Wiring
- Connect:
  - SDA ↔ SDA
  - SCL ↔ SCL
  - GND ↔ GND
  - +5V (the USB C connection must providepowre at or near +5V to power the remote sensors and overcome resistive losses.)

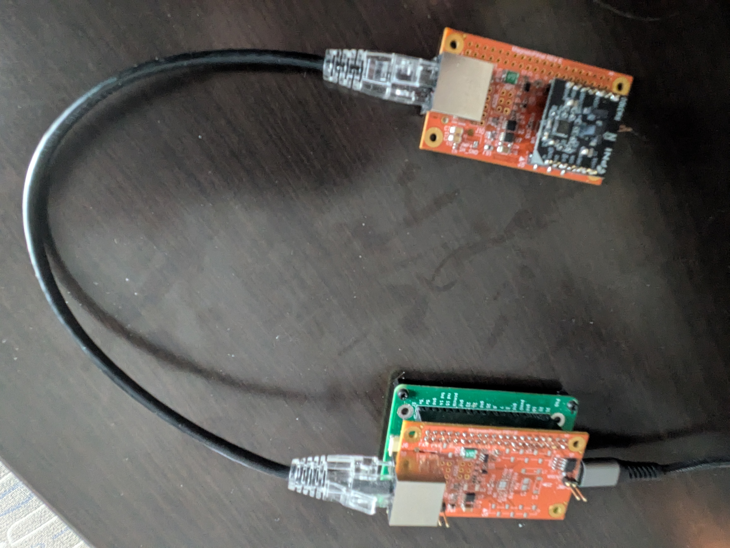
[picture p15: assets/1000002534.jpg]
Sensor Wiring Detail

*Fig. 2: Close-up of the sensor wiring and connector pinout.*

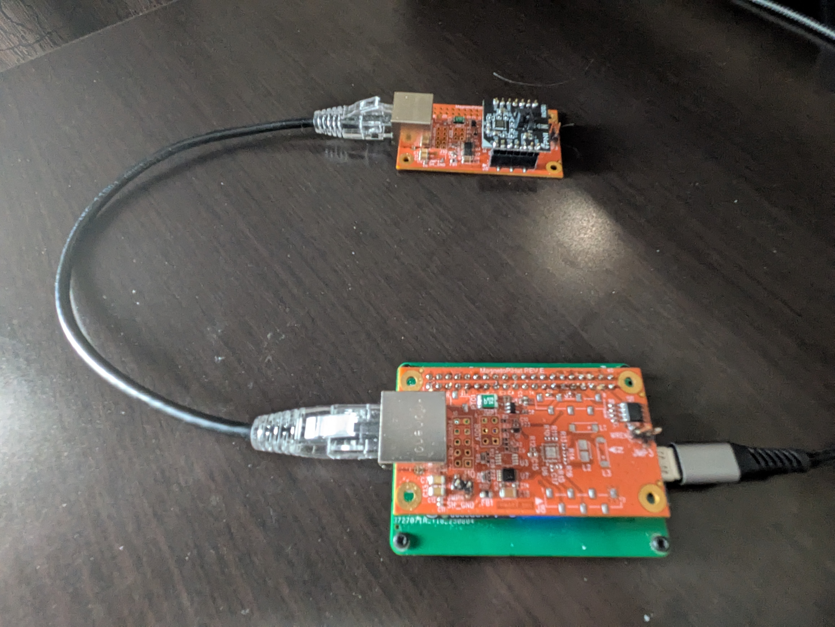
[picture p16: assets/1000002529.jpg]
Pololu Adapter Detail

*Fig. 2a: Detail of the Pololu adapter connections.*
- Confirm pull-ups are present on SDA/SCL (many boards include them).

## Linux device path
- The adapter appears as a ttyACM device (e.g., /dev/ttyACM0).
- The full setup should configue a device named /dev/ttyMAG0 that symlinks to the correct ACM device, but you can also use the ACM path directly.
- If the adapter doesn't appear, try replugging it and check dmesg or lsusb for clues. You should see a new device with a name like "Pololu USB-to-I²C Adapter" and an associated ACM device number.
- Check dmesg or lsusb for details; examples are in assets.

## Stable permissions and naming
- A sample udev rule is provided at install/99-PololuI2C.rules. To install:
```
sudo cp install/99-PololuI2C.rules /etc/udev/rules.d/
sudo udevadm control --reload-rules
sudo udevadm trigger
```
- After replugging the adapter, confirm permissions and any symlink names defined in your rule.

## Verifying connectivity
- Use mag-usb's quick check flag:
```
./mag-usb -Q                      # uses default /dev/ttyMAG0
./mag-usb -O /dev/ttyACM0 -Q      # override if udev rule not installed
```
- If you see permission errors, check your udev setup and group membership (dialout or equivalent on your distro), or run temporarily with sudo (not recommended long-term).

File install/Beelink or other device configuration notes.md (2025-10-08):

## Beelink or other device configuration notes

### Creating a udev rules file for the Pololu adapter.
The idea here is to create a predicable entry in /dev for the software to connect to.

The device entry name used is /dev/ttyMAG0.  This is used bu the software as the default device entry path to open.

This default may be overridden from the command line using a parameter specification like ' _-P /dev/ttyACMx_ ' if needed.

##### From: 99-PololuI2C.rules
```
# Attached to USB-A connector on front of LattePanda Sigma (LP-Sig0)
#-------------------------------------------------------------------------
# Pololu dodumentation for installing on Windows indicates that the VID/Pid pairs
# are:
#     USB\VID_1FFB&PID_2502  (for the 'Pololu Isolated USB-to-I2C Adapter')
#     USB\VID_1FFB&PID_2503  (Pololu Isolated USB-to-I2C Adapter with Isolated Power') (I think)
#
# $ lsusb
# ...
# 'Pololu Corporation Pololu Isolated USB-to-I2C Adapter with Isolated Power'
# Bus 003 Device 023: ID 1ffb:2503
# ...
#
# $ lsusb -t
# ...
# /:  Bus 003.Port 001: Dev 001, Class=root_hub, Driver=xhci_hcd/12p, 480M
#    |__ ...
#    |__ ...
#    |__ Port 006: Dev 023, If 0, Class=Communications, Driver=cdc_acm, 12M
#    |__ Port 006: Dev 023, If 1, Class=CDC Data, Driver=cdc_acm, 12M
#    |__ ...
# ...
#
# udevadm info --name=/dev/ttyACM2 --attribute-walk
#  looking at device '/devices/pci0000:00/0000:00:14.0/usb3/3-7/3-7.1/3-7.1.2/3-7.1.2:1.0/tty/ttyACM2':
#    KERNEL=="ttyACM2"
#    SUBSYSTEM=="tty"
#    DRIVER==""
#    ATTR{power/async}=="disabled"
#  ...
#
#  looking at parent device '/devices/pci0000:00/0000:00:14.0/usb3/3-7/3-7.1/3-7.1.2/3-7.1.2:1.0':
#    KERNELS=="3-7.1.2:1.0"
#    SUBSYSTEMS=="usb"
#    DRIVERS=="cdc_acm"
#  ...
# ...
# 
# Reload rules:
# 		$ sudo udevadm control --reload-rules && sudo udevadm trigger
# Test:
# 		$ ls .l /dev/ttyMAG0
#
KERNEL=="ttyACM[0-9]*", SUBSYSTEM=="tty", ATTRS{idVendor}=="1ffb", ATTRS{idProduct}=="2503", SYMLINK+="ttyMAG0"
```

```
$ udevadm info --name=/dev/ttyACM2 --attribute-walk

Udevadm info starts with the device specified by the devpath and then
walks up the chain of parent devices. It prints for every device
found, all possible attributes in the udev rules key format.
A rule to match, can be composed by the attributes of the device
and the attributes from one single parent device.

  looking at device '/devices/pci0000:00/0000:00:14.0/usb3/3-6/3-6:1.0/tty/ttyACM2':
    KERNEL=="ttyACM2"
    SUBSYSTEM=="tty"
    DRIVER==""
    ATTR{power/async}=="disabled"
    ATTR{power/control}=="auto"
    ATTR{power/runtime_active_kids}=="0"
    ATTR{power/runtime_active_time}=="0"
    ATTR{power/runtime_enabled}=="disabled"
    ATTR{power/runtime_status}=="unsupported"
    ATTR{power/runtime_suspended_time}=="0"
    ATTR{power/runtime_usage}=="0"

  looking at parent device '/devices/pci0000:00/0000:00:14.0/usb3/3-6/3-6:1.0':
    KERNELS=="3-6:1.0"
    SUBSYSTEMS=="usb"
    DRIVERS=="cdc_acm"
    ATTRS{authorized}=="1"
    ATTRS{bAlternateSetting}==" 0"
    ATTRS{bInterfaceClass}=="02"
    ATTRS{bInterfaceNumber}=="00"
    ATTRS{bInterfaceProtocol}=="00"
    ATTRS{bInterfaceSubClass}=="02"
    ATTRS{bNumEndpoints}=="01"
    ATTRS{bmCapabilities}=="6"
    ATTRS{iad_bFirstInterface}=="00"
    ATTRS{iad_bFunctionClass}=="02"
    ATTRS{iad_bFunctionProtocol}=="00"
    ATTRS{iad_bFunctionSubClass}=="02"
    ATTRS{iad_bInterfaceCount}=="02"
    ATTRS{interface}=="Pololu Isolated USB-to-I2C Adapter with Isolated Power"
    ATTRS{physical_location/dock}=="no"
    ATTRS{physical_location/horizontal_position}=="left"
    ATTRS{physical_location/lid}=="no"
    ATTRS{physical_location/panel}=="top"
    ATTRS{physical_location/vertical_position}=="upper"
    ATTRS{power/async}=="enabled"
    ATTRS{power/runtime_active_kids}=="0"
    ATTRS{power/runtime_enabled}=="enabled"
    ATTRS{power/runtime_status}=="suspended"
    ATTRS{power/runtime_usage}=="0"
    ATTRS{supports_autosuspend}=="1"

```

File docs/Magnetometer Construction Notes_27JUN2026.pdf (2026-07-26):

# Magnetometer Construction Notes

Mark Braunstein WA4KFZ
27 June 2026
Revision: 1.0

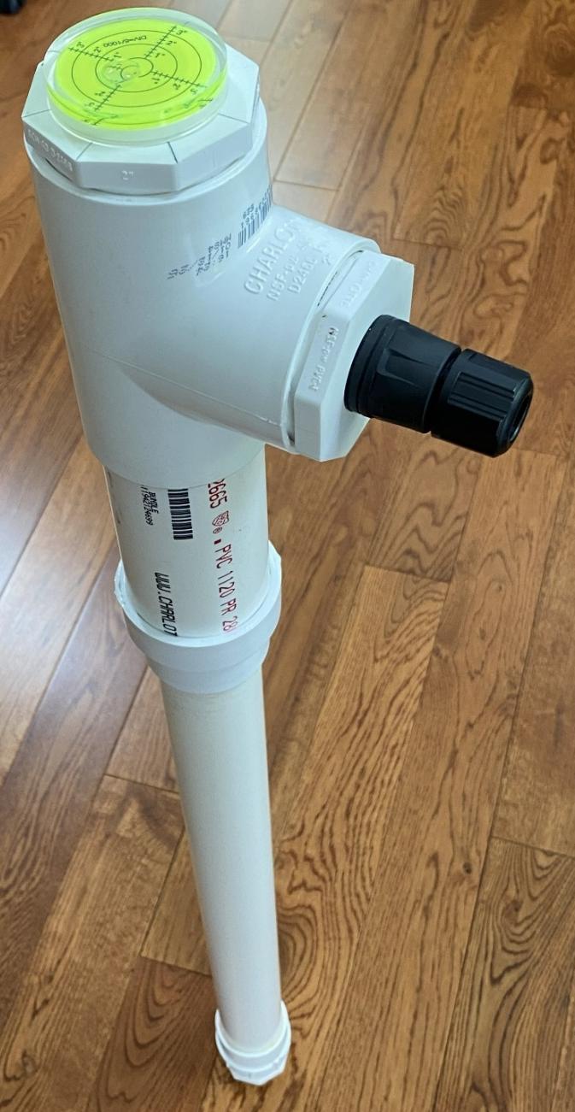
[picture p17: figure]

i

## Document Revisions

Date | Revision | Author | Notes
27 June 2026 | 1.0 | Mark Braunstein WA4KFZ | Initial release

ii

## Contents

Magnetometer Construction Notes | Error! Bookmark not defined.

Suggested Software Improvement to Aid in Installation .....Error! Bookmark not defined.

iii

## Table of Figures

Figure 1 – Location of the three magnetic coil assemblies on the RM3100 breakout board.
Be sure to avoid damaging the coils during magnetometer assembly | 1
Figure 2 – A simple method to locate the center of the plug | 3
Figure 3 – Bubble level installed on the PVC plug and oriented with the drawn lines on the
top surface | 4
Figure 4 – Interior view of the PVC plug after drilling with the Forstner bit. Note the 1/16” hole to aid in keeping the bit centered during the drilling process. The recessed hole depth
is approximately the thickness of the RJ45 adapter hex nut | 5
Figure 5 – Drilling the 1” hole on the top surface of the plug | 6
Figure 6 – RJ45 bulkhead adapter installed using the hex coupling nut. Finger-tighten the
hex nut first, then use needle nose pliers to tighten the nut fully | 7
Figure 7 – RJ45 bulkhead adapter installed on the PVC plug and ready for cable attachment.
| 8
Figure 8 – Magnetometer housing construction using PVC plumbing pipe and fittings.........9
Figure 9 - Inserting the patch cord through the PVC Tee fitting | 10
Figure 10 - The portion of the rubber boot that protects the connector release lever was cut
off using a utility knife | 11
Figure 11 - Wrap 4mm-thick closed cell foam material around the PC board and gently push
the assembly into the bottom end of the 1-1/2” PVC pipe | 12
Figure 12 - The remote PC board installed at the bottom end of the 1-1/2" PVC pipe. The PC
board is held in place using 4mm-thick closed cell foam | 13
Figure 13 - Orientation of PC board inside the PVC pipe. The tall sensing coil points toward
"North." | 14
Figure 14 – Silicone caulk applied to end cap of magnetometer housing | 15
Figure 15 - Silicone caulk applied to top and connector ports of the magnetometer housing.
| 15
Figure 16 - Entering the command line data to start runMag. Here, the grid square was used
as the node ID parameter | 18
Figure 17 - Example data output once runMag is operational. The data is updated at one-second intervals. "rt" refers to the remote temperature sensor. "x", "y" and "z" refer to the
RM3100 magnetometer board output values | 18
Figure 18 – Assembled IP68-rated female-female coupler | 19
Figure 19 - Vinyl electrical tape wrapping to provide further moisture protection | 19
Figure 20 - Initial installation of the magnetometer. The hole is backfilled halfway with loose
soil to support the unit during final orientation | 20

iv

Figure 21 - Magnetometer field equipment configuration. The magnetometer was rotated
while observing the data displayed on the laptop computer | 21
Figure 22 – Field equipment configuration used during the magnetometer orientation step. A 10ft CAT6 cable connected the magnetometer to the Raspberry Pi (inside the cardboard box). The laptop computer, Raspberry Pi and the wireless access point were connected using a network hub. A 12V battery (inside the green box) and 12V to 5V DC-DC converter
were used to power the equipment | 21
Figure 23 - Relationship between the various parameters associated with the
magnetometer and the displayed data. Orientation is optimized when the "y" values are
minimized and the "z" values are maximized | 23
Figure 24 – The rubber patio paver was modified by cutting a hole in the center and creating
a slot on one side | 24
Figure 25 - The magnetometer installed and properly oriented. The rubber paver and bricks cover the weed block material. The fencing and road reflector increase visibility and
prevent accidental damage during lawn care | 26

## Caution

The RM3100 breakout board contains three magnetic coil assemblies (Figure 1) that are very fragile. During construction, be sure to carefully handle the remote PC board and avoid inadvertently impacting the coils with tools or other objects.

Figure 1 – Location of the three magnetic coil assemblies on the RM3100 breakout board. Be sure to avoid damaging the coils during magnetometer assembly.

## Tools

- 4” bench vise or similar
- Hacksaw or miter saw (to cut PVC pipe sections)
- 3/8” or larger variable speed drill
- 1-3/8” Forstner drill bit
- 1/16” twist drill bit
- Palm sander
- 100-grit sandpaper
- 220-grit sandpaper
- Straight edge ruler
- Fine point permanent marker pen
- Long nose pliers
- Scissors or utility knife

## PVC Plug Surface Preparation

Two PVC SPG plugs are used in the construction of the magnetometer housing: one on top to mount a bubble level indicator and one on the side to mount an RJ45 bulkhead adapter.

The “flat” surfaces on these plugs are unfortunately not flat enough for our applications and need to be modified.

- Place the 2” PVC SPG plugs in a bench vise with the flat side up.
- Using a palm sander with 100-grit sandpaper, press firmly to smooth the top surface of the plug. Move the sander in a circular motion. When sufficiently smoothed, there should be no “dips” in the surface. The sanded PVC will have a dull, white finish.
- Using 220-grit sandpaper, sand the top surface of the plug by hand. This further flattens the surface and improves hardware retention for the bubble level and RJ45 bulkhead adapter.

## Bubble Level Attachment

A 50 x 10mm bubble level is adhered to the top PVC plug. During magnetometer installation in the ground, this bubble level aids in the Z-axis alignment process. The bubble level is attached using the provided double-sided tape.
To center the bubble level on the plug’s top surface, use a marker pen to draw lines from one octagonal edge to the opposite edge (Figure 2). The line will pass through the center of the plug. Repeating the process will define the center of the plug as the intersection of the lines.
When placing the bubble level on the flat surface of the plug, use the drawn lines to align with those of the bubble level (Figure 3). This will aid in magnetometer orientation during ground installation.

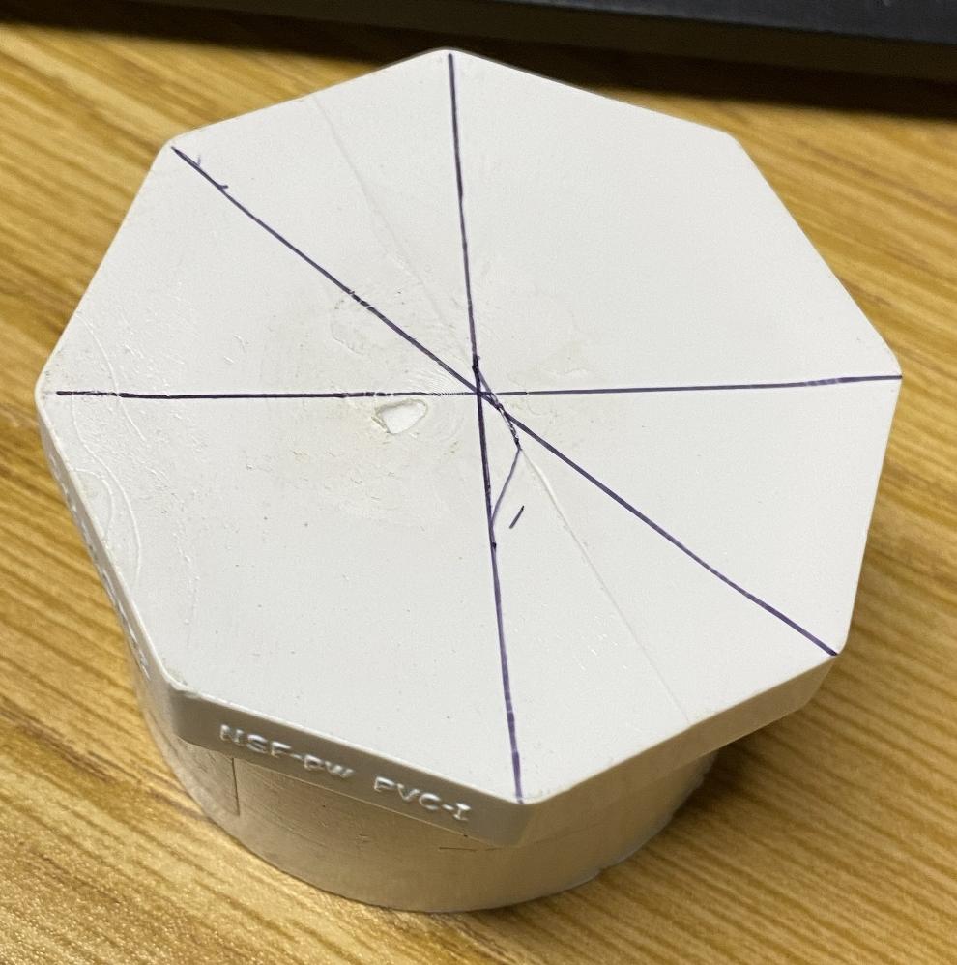
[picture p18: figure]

Figure 2 – A simple method to locate the center of the plug.

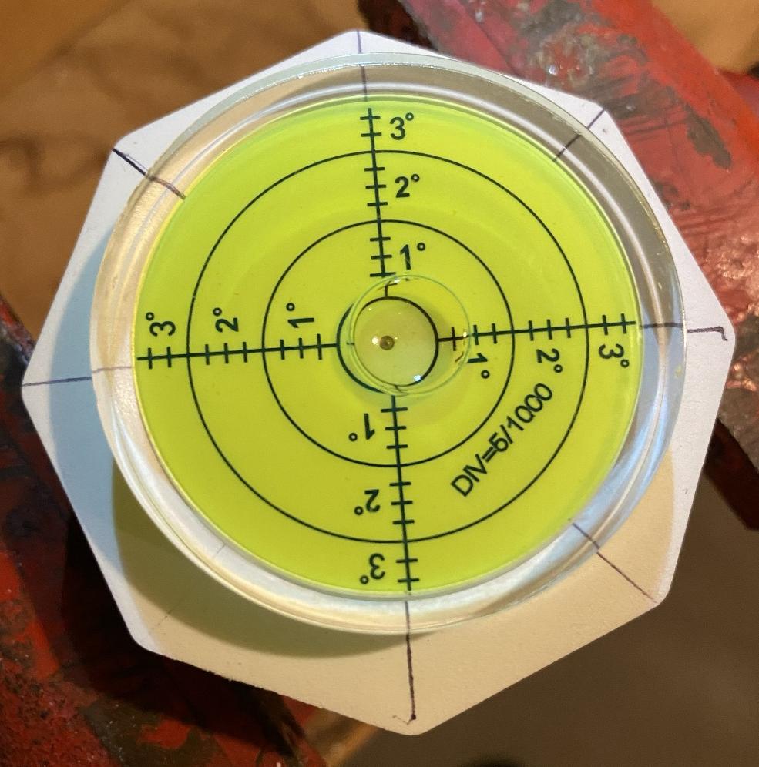
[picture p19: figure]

Figure 3 – Bubble level installed on the PVC plug and oriented with the drawn lines on the top surface.

## RJ45 Bulkhead Adapter Attachment

A 1” hole is drilled in a PVC SPG plug to accommodate insertion of the RJ45 bulkhead adapter. The adapter barely has enough thread length to pass through the drilled PVC SPG plug to allow installation of the coupling hex nut. To provide additional thread length, it is necessary to countersink the inside surface of the plug. A 1-3/8” Forstner bit (commonly used for woodworking applications) is used to mill the inside surface. The milling depth required is approximately the height of coupling hex nut. The Forstner bit allows the milled hole to retain a flat surface.

- Drill a 1/16” hole through the center of the plug. This small hole serves to align the Forstner bit during operation.
- With the Forstner bit installed, run the drill at high speed and gently press the bit into the plug. The Forstner bit has sharp edges that can “catch” the PVC plastic and cause “bucking” of the drill. Use slow, gentle pressure to run the bit against the PVC plastic. Keep the bit as perpendicular to the plug as possible. With sufficient downward pressure, plastic chips will be “shaved” from the inside surface of the plug. Periodically stop the drill and check the depth of the milled area. It may be necessary to slightly tilt the Forstner bit to keep the milled area perpendicular to the centerline of the plug. Continue milling until the depth of the cut equals the height of the coupling hex nut (Figure 4).

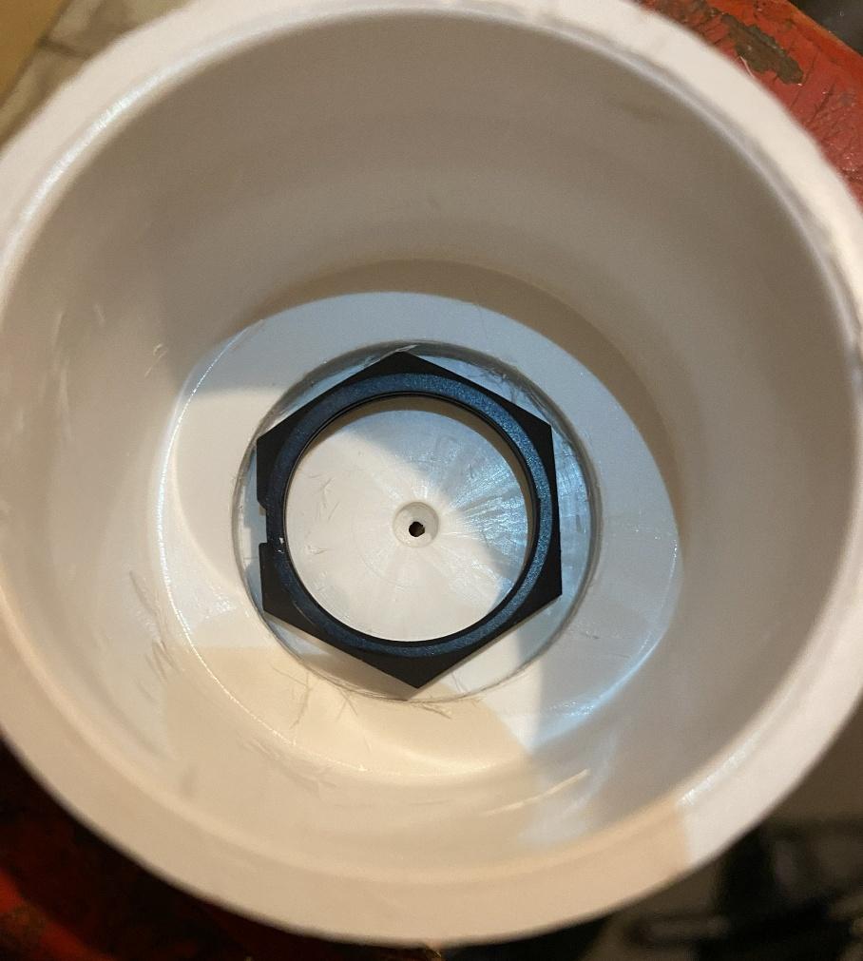
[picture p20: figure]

Figure 4 – Interior view of the PVC plug after drilling with the Forstner bit. Note the 1/16” hole to aid in keeping the bit centered during the drilling process. The recessed hole depth is approximately the thickness of the RJ45 adapter hex nut.
- Remove the Forstner bit and install the stepped drill bit.

- Turn the plug over and secure it in the bench vise. Use the stepped drill bit to drill a 1” hole, starting on the top surface of the plug (Figure 5).

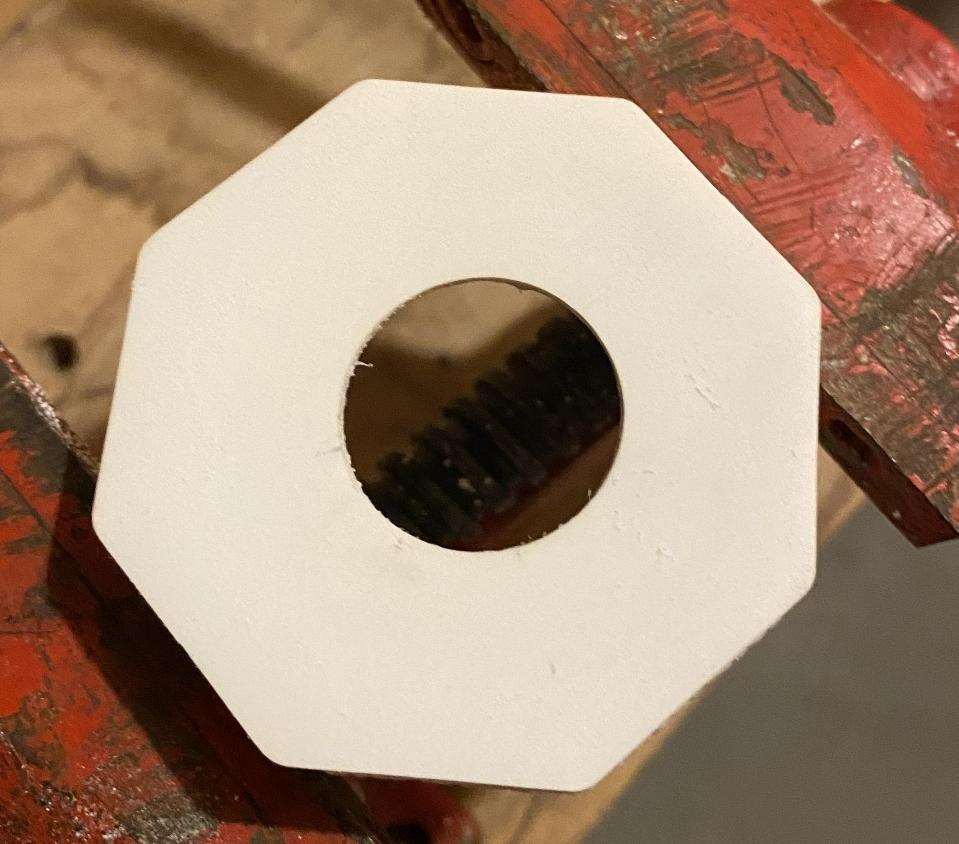
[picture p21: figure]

Figure 5 – Drilling the 1” hole on the top surface of the plug.
- Turn the plug over again and repeat the drilling process from the inside of plug. This is necessary to ensure that the 1” diameter hole is uniform through the plug’s face.
- Insert the RJ45 bulkhead adapter into the modified plug. Install the coupling hex nut on the inside of the plug. Finger-tighten the nut, then use a long pair of needle nose pliers to span the hex nut and gently tighten the connection (Figure 6). The rubber gasket on the adapter (located on the top surface of the plug) provides the necessary weatherproofing for the installation (Figure 7).

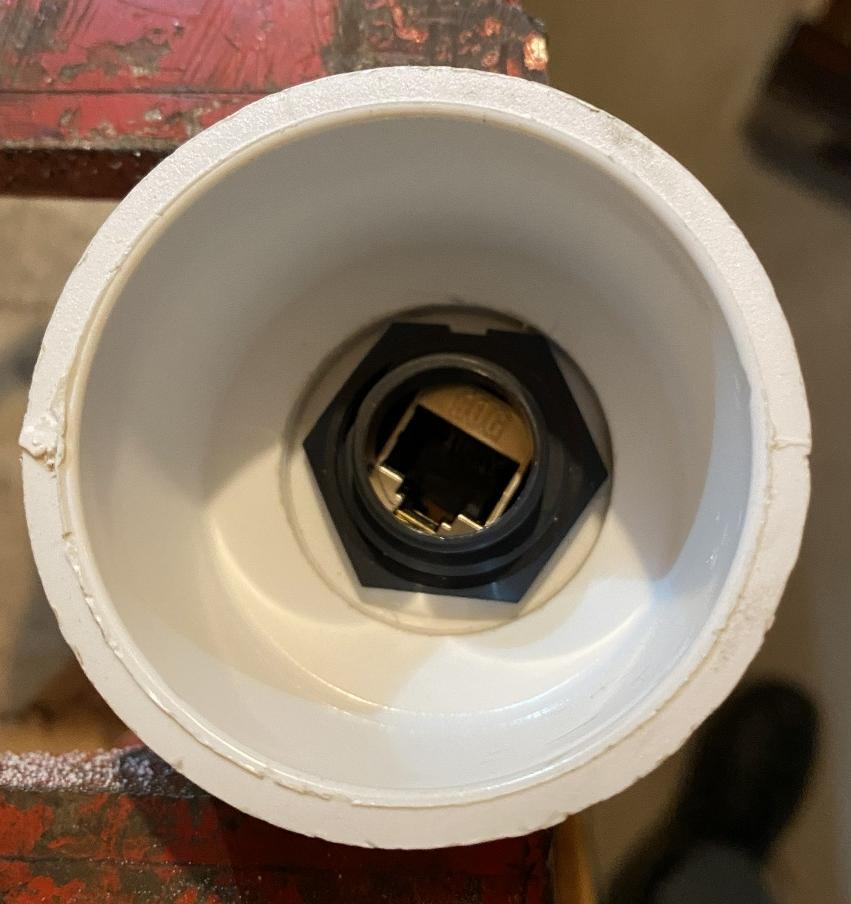
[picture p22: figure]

Figure 6 – RJ45 bulkhead adapter installed using the hex coupling nut. Finger-tighten the hex nut first, then use needle nose pliers to tighten the nut fully.

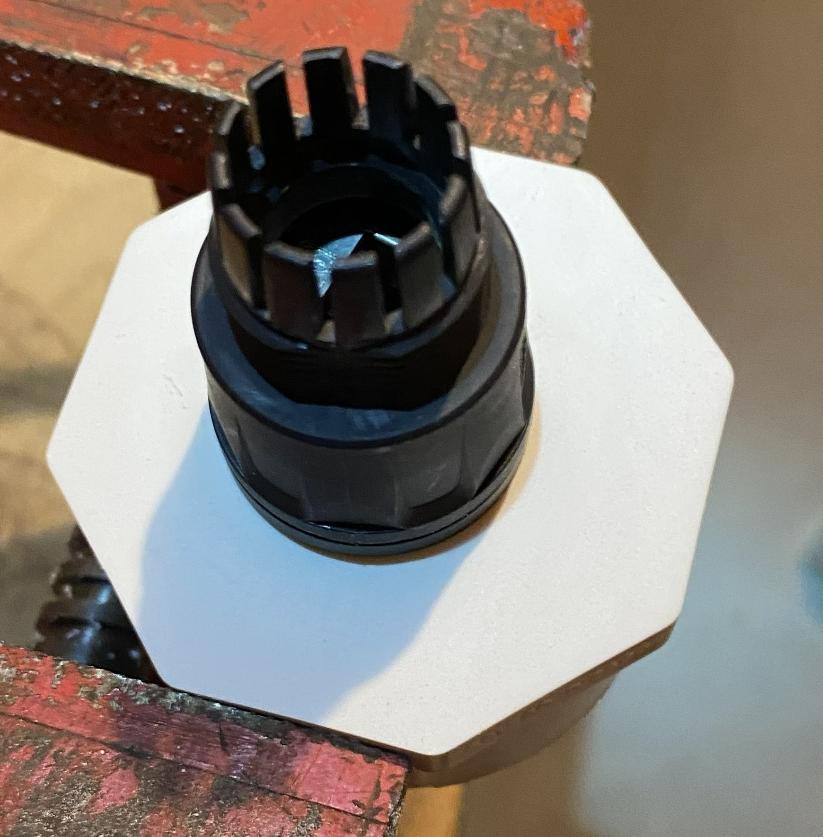
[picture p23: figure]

Figure 7 – RJ45 bulkhead adapter installed on the PVC plug and ready for cable attachment.

## Housing Construction

The magnetometer housing (Figure 8) is constructed from Schedule 40 PVC pipe (commonly found at hardware stores) and associated PVC fittings. The pipe sections can be cut to length using a hacksaw or miter saw. Construction of the housing is shown in the figure. Use PVC solvent cement to join the indicated fittings to the pipe sections. The PVC SPG plugs are pressed into the tee-fitting by hand and weather sealed with wrapped tape or silicone caulking. If necessary, a large wrench can be used to loosen these plugs for removal.

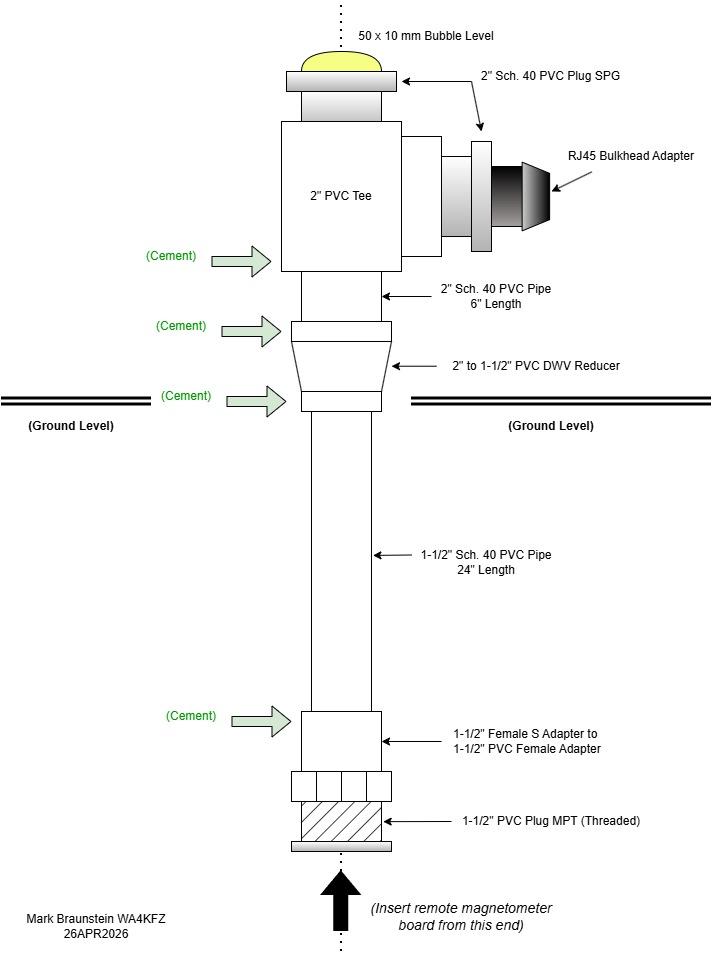
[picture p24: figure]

Figure 8 – Magnetometer housing construction using PVC plumbing pipe and fittings.

## Remote PC Board Installation

Before installing the remote PC board inside the housing, feed the 3ft CAT6 patch cable through the 2” PVC Tee fitting (Figure 9). The cable will then protrude through the bottom of the 1-1/2” pipe end.

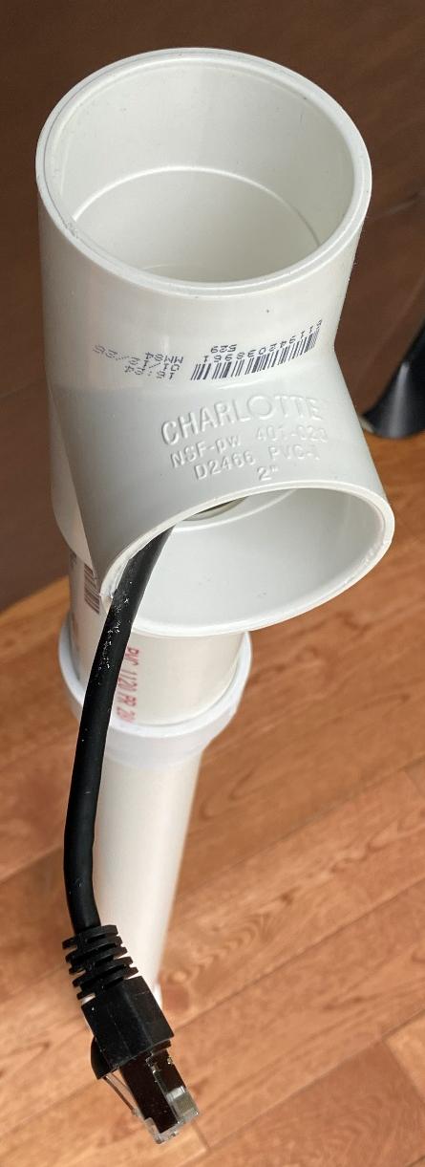
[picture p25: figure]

Figure 9 - Inserting the patch cord through the PVC Tee fitting.
On the connector that plugs into the RJ45 bulkhead adapter, it was necessary to cut off the protective rubber boot around the connector release tab (Figure 10). A utility knife can easily cut through the material.

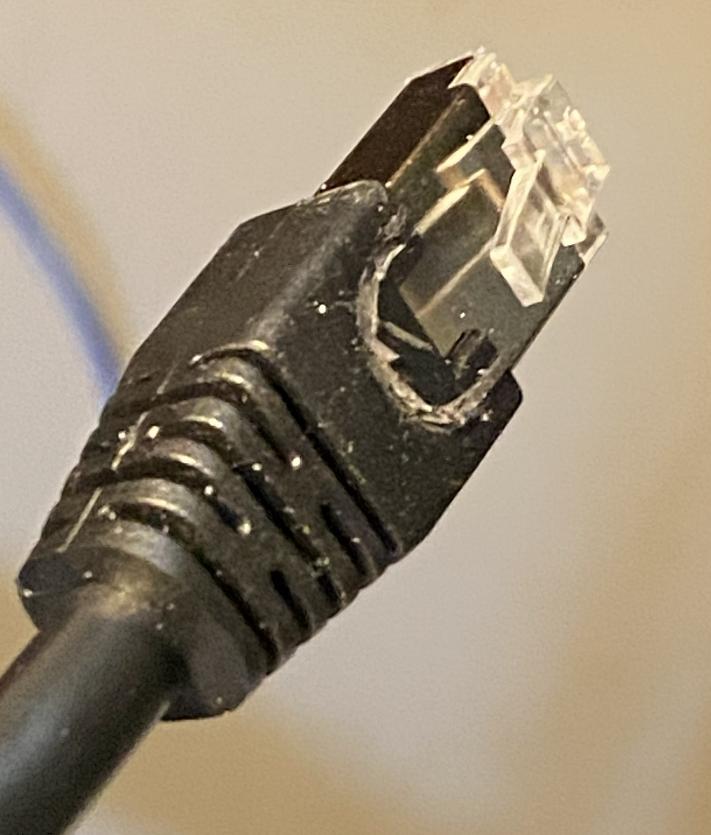
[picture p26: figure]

Figure 10 - The portion of the rubber boot that protects the connector release lever was cut off using a utility knife.
Plug one end of the cable into the remote PC board connector. The remote PC board is installed in the magnetometer housing from the bottom end. Since the board’s width is less than the interior diameter of the 1-1/2” PVC pipe, it is necessary to “shim” the board to keep it centered and secured. If a 3D printed fixture is not available, a 4” x 4” piece of 4mm-thick closed cell foam can be used to wrap around the board (Figure 11) and create a friction fit to hold the board in place (Figure 12).

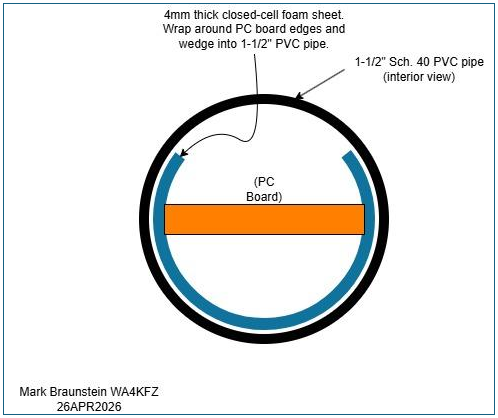
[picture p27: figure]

Figure 11 - Wrap 4mm-thick closed cell foam material around the PC board and gently push the assembly into the bottom end of the 1-1/2” PVC pipe.

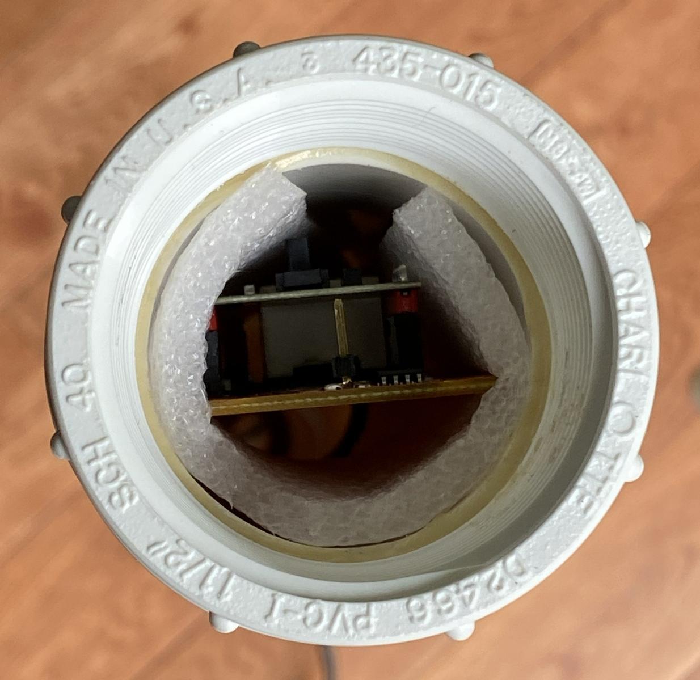
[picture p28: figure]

Figure 12 - The remote PC board installed at the bottom end of the 1-1/2" PVC pipe. The PC board is held in place using 4mm-thick closed cell foam.
When inserting the PC board and foam material, gently push the combination into the end of the pipe. If it becomes necessary to remove the PC board, use long nose pliers and grab the foam material while aiding removal with your hand. Do not use the pliers on the PC board itself; you’ll risk damaging the board.

The PC board is oriented so that the tall sensor coil faces in the direction defined as “North” during the ground installation step (Figure 13).

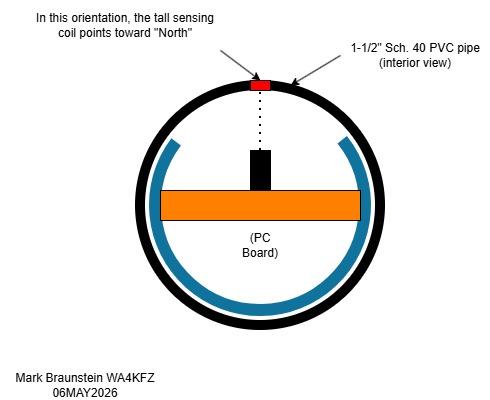
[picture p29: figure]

Figure 13 - Orientation of PC board inside the PVC pipe. The tall sensing coil points toward "North."
Once the PC board has been installed in the housing, plug the other end of the cable into the RJ45 bulkhead adapter. Firmly press the PVC plug with the adapter into the 2” PVC Tee. In the final step, the bottom threaded plug is inserted once the PC board has been installed. Using a large wrench, tighten the plug into the fitting until it stops rotating. Do not overtighten the plug.

## Environmental Sealing

Most of the PVC pipe and fitting connections are joined using PVC cement. For the PVC plugs used with the bubble level, RJ45 adapter and bottom (threaded) board insertion plug, it is necessary to seal the connections to prevent moisture intrusion. These connections can be sealed with wrapped tape (vinyl electrical tape and self-adhering rubber tape) or silicone caulking (Figure 14) (Figure 15).

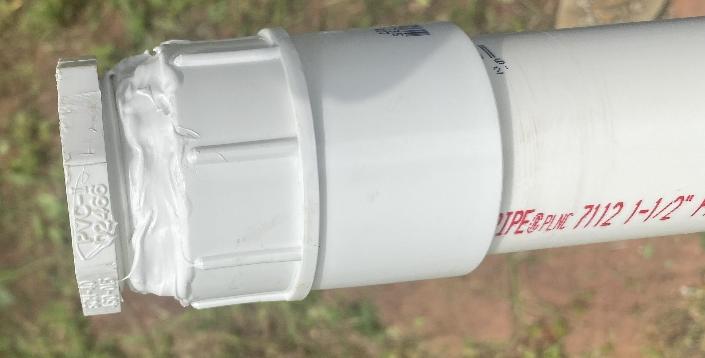
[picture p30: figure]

Figure 14 – Silicone caulk applied to end cap of magnetometer housing.

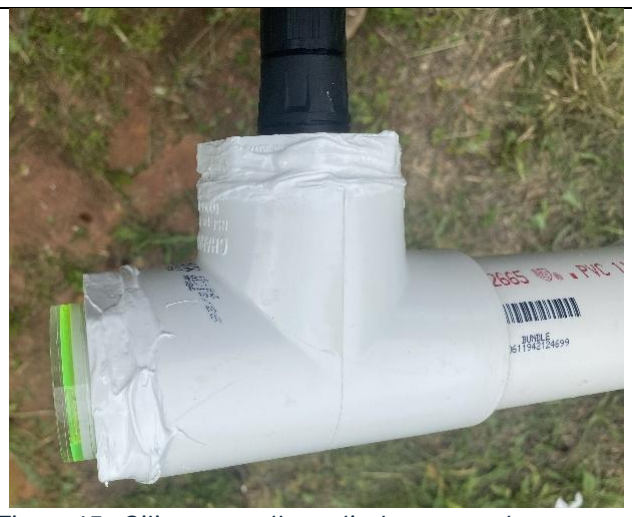
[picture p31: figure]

Figure 15 - Silicone caulk applied to top and connector ports of the magnetometer housing.

17

## Bill of Materials (as of 13JUN2026)

Description | Qty. | Mfr. | Mfr. Part No. | Vendor | Notes
2 in. PVC Schedule 40-Plug SPG | 2 | Charlotte Pipe | PVC021181800HD | Home Depot
2 in. PVC Schedule 40 S x S x S Tee | 1 | Charlotte Pipe | PVC024001600HD | Home Depot
2 in. x 2 ft. PVC DWV Schedule 40 Pipe | 1 | Charlotte Pipe | PVC072000200HA | Home Depot | Cut to 6-inch length
1 1/2 in. x 2 in. PVC DWV Hub x Hub Increaser/Reducer Coupling | 1 | Charlotte Pipe | PVC001020600HD | Home Depot
1-1/2 in. x 2 ft. PVC DWV Schedule 40 Pipe | 1 | Charlotte Pipe | PVC071120200HA | Home Depot
1-1/2 in. PVC Schedule 40 Female S x FPT Adapter | 1 | Charlotte Pipe | PVC021011400HD | Home Depot
1-1/2 in. PVC Schedule 40-Plug MPT | 1 | Charlotte Pipe | PVC021131400HD | Home Depot
CPLR C6A SHLD RJ45 IP68 PNL MT | 1 | L-Com | CG-C6A-FP | L-com
Monoprice Cat6A 3ft Black Patch Cable Double Shielded (S/FTP) 26AWG 10G Pure Bare Copper Snagless RJ45 Fullboot Series Ethernet Cable | 1 | Monoprice | 124335 | Amazon
Circular Bubble Level with Double Sided Adhesive Bottom Spirit Levels Leveling Measuring Tools (50x10mm), F-color | 1 | SIZIKJXGHWYI | J65 | Amazon | Mounted using double-sided adhesive tape
White EVA Foam Sheet, 4mm Thick Foam Sheet for Cosplay, 59"x13.9" with High Density 86kg/m3 Eva Foam Roll for Art Craft Costume DIY Project (4mm White) | 1 | Do²ping | | Amazon | Many equivalent closed-cell foam products available
Silicone Caulk, 10.1oz., Window and Door Sealant, White | 1 | GE | 2811093 | Home Depot | Requires caulk gun. Alternate products are readily available.

## Software Testing

The Raspberry Pi software is installed from the rm3100-runMag GitHub repository. The installation process is not described in this document.
To conduct a functional test of the magnetometer, the command line shown in the latest GitHub readme section was entered at the command prompt:
./runMag -b 1 -j -R 1f -r -H -M 23 -c 400 S <callsign or node id>
In Figure 16, the local grid square was temporarily used in place of the callsign or node ID.

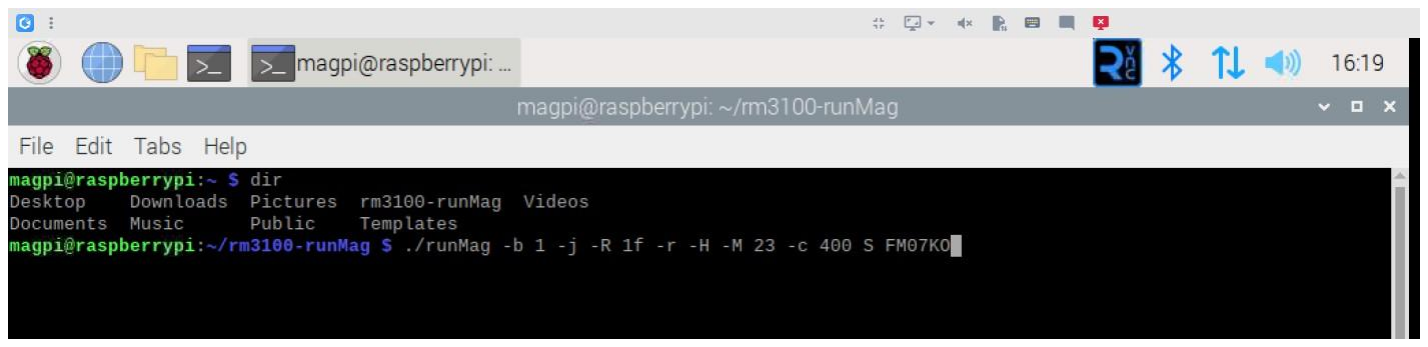
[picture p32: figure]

Figure 16 - Entering the command line data to start runMag. Here, the grid square was used as the node ID parameter.
Once the command line has been executed, the program will display the temperature reading and XYZ values from the magnetometer in one-second intervals. An example of the displayed data is shown in Figure 17.

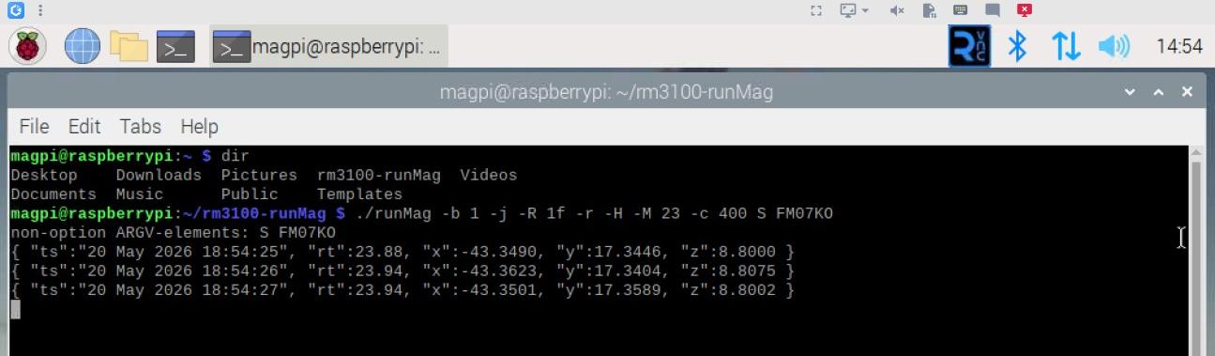
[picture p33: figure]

Figure 17 - Example data output once runMag is operational. The data is updated at one-second intervals. "rt" refers to the remote temperature sensor. "x", "y" and "z" refer to the RM3100 magnetometer board output values.
To stop program execution, type Ctrl-C.

## Site Installation

## Comment

Note: the cable assemblies and magnetometer installation procedure described in this section were specific to the author’s location. Your installation needs may vary. Select the installation methods best suited for your location.

## Cable Assemblies

Pre-made CAT6 cable assemblies were used during installation to avoid the need to purchase connector crimping tools. A 100ft run of CAT6 cable was installed inside a buried 4” corrugated drainage pipe along with coaxial cables used for other antennas. The magnetometer was located approximately 25ft away from the exit point of the pipe, requiring the installation of a direct-burial CAT6 extension cable. An IP68-rated female-female coupler was used to join the two cables (Figure 18). Although the coupler has an IP68 rating, an additional wrapping of vinyl electrical tape was used to provide further moisture protection (Figure 19). The coupler was then buried in the ground along the trenched cable path.

Figure 18 – Assembled IP68-rated female-female coupler.

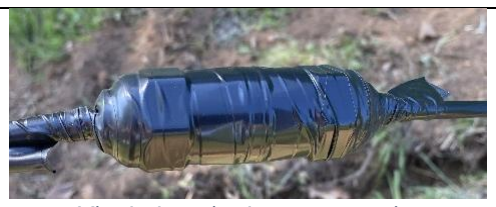
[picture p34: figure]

Figure 19 - Vinyl electrical tape wrapping to provide further moisture protection.

## Magnetometer Alignment

The magnetometer was installed in a hole approximately 2ft deep. The hole was dug using a digging bar and a post-hole digger. The magnetometer was placed in the hole and backfilled approximately halfway with loose soil to keep the unit upright (Figure 20). A stick was used to gently compact the soil. The bubble level on top of the unit was used to ensure that vertical orientation was maintained. The compass app on an iPhone (set to the magnetic compass reading), was used to roughly orient the magnetometer toward magnetic North.

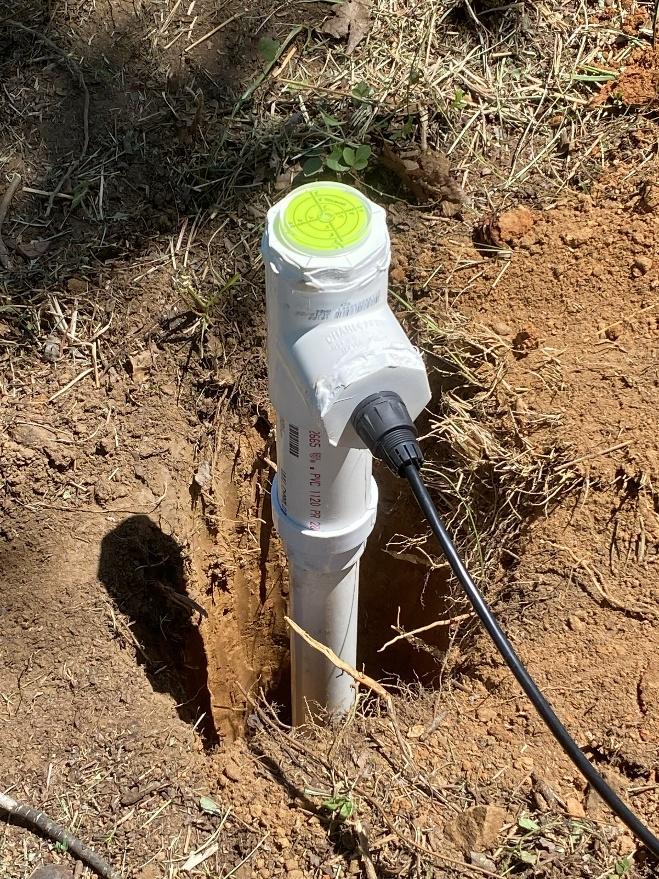
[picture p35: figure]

Figure 20 - Initial installation of the magnetometer. The hole was backfilled halfway with loose soil to support the unit during final orientation.
Final alignment of the magnetometer required rotation of the housing, orienting the H and E axes based on the local magnetic field. To perform this field alignment step, the Raspberry Pi was collocated with the magnetometer (through a 10ft CAT6 cable) and operated in a “headless” configuration. The Raspberry Pi continuously polled the remote sensor board inside the magnetometer, providing readings corresponding to the orientation. A virtual connection was established between a laptop computer and the Raspberry Pi using RealVNC remote access software. Since newer versions of RealVNC require an internet cloud connection, connectivity was provided through a Mikrotik SXTsq5 wireless access point directed toward a home WiFi router inside the station location. A 12V battery was used to power the field equipment and a 12V to 5V DC-DC converter was used to power the Raspberry Pi. A network switch was used to interconnect the laptop computer, Raspberry Pi and access point. This configuration is shown in Figure 21 and Figure 22.

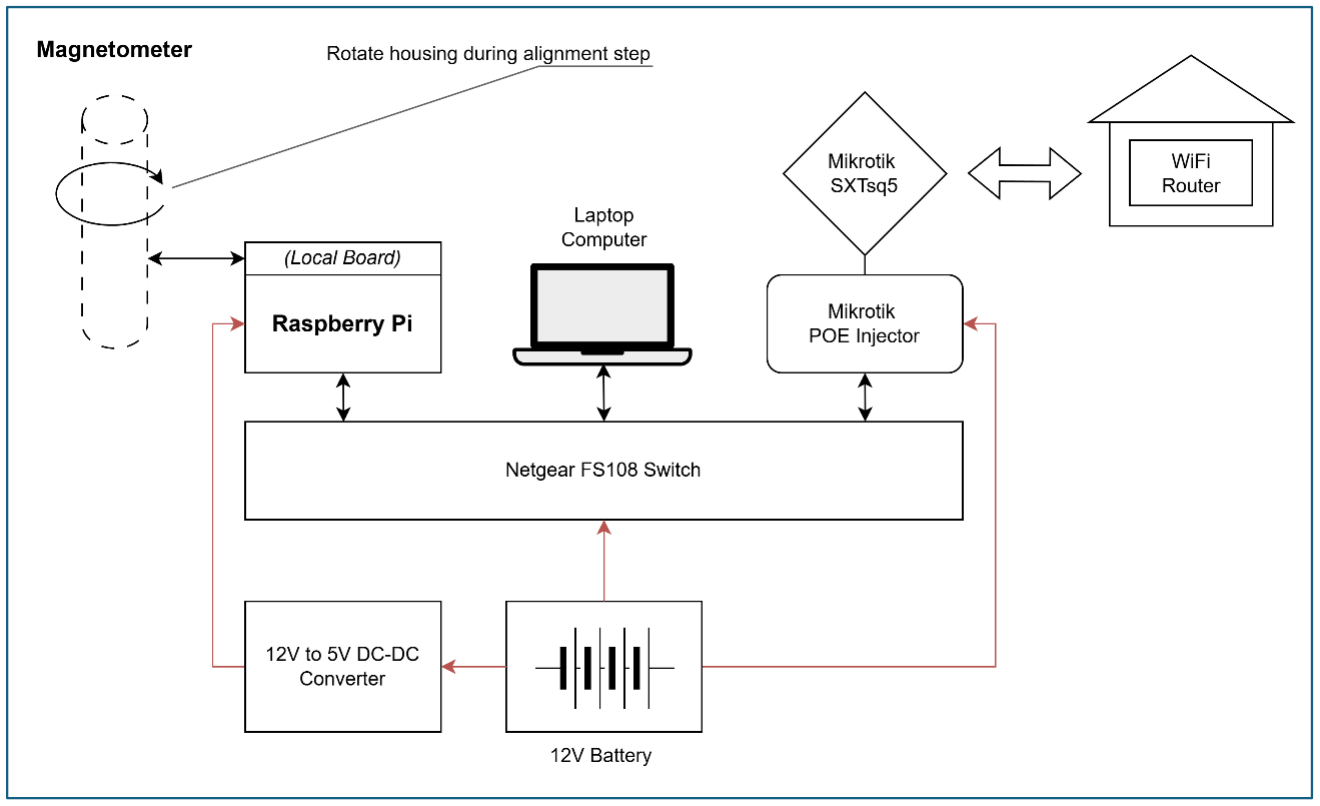
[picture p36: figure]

Figure 21 - Magnetometer field equipment configuration. The magnetometer was rotated while observing the data displayed on the laptop computer.

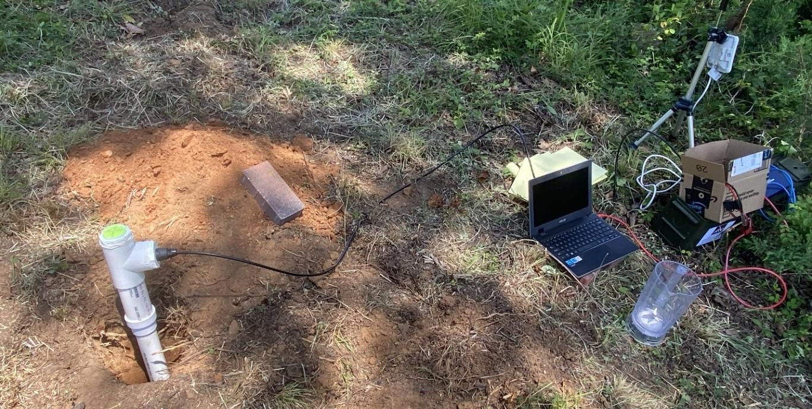
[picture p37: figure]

Figure 22 – Field equipment configuration used during the magnetometer orientation step. A 10ft CAT6 cable connected the magnetometer to the Raspberry Pi (inside the cardboard box). The laptop computer, Raspberry Pi and the wireless access point were connected using a network hub. A 12V battery (inside the green box) and 12V to 5V DC-DC converter were used to power the equipment.

## Orientation Process

Although the magnetometer is oriented in accordance with the HEZ coordinate system, the runMag software displays the outputs of the X, Y and Z sensors on the RM3100 breakout board. The relationship between these vectors and the XYZ columns in the displayed data are shown in Figure 23.

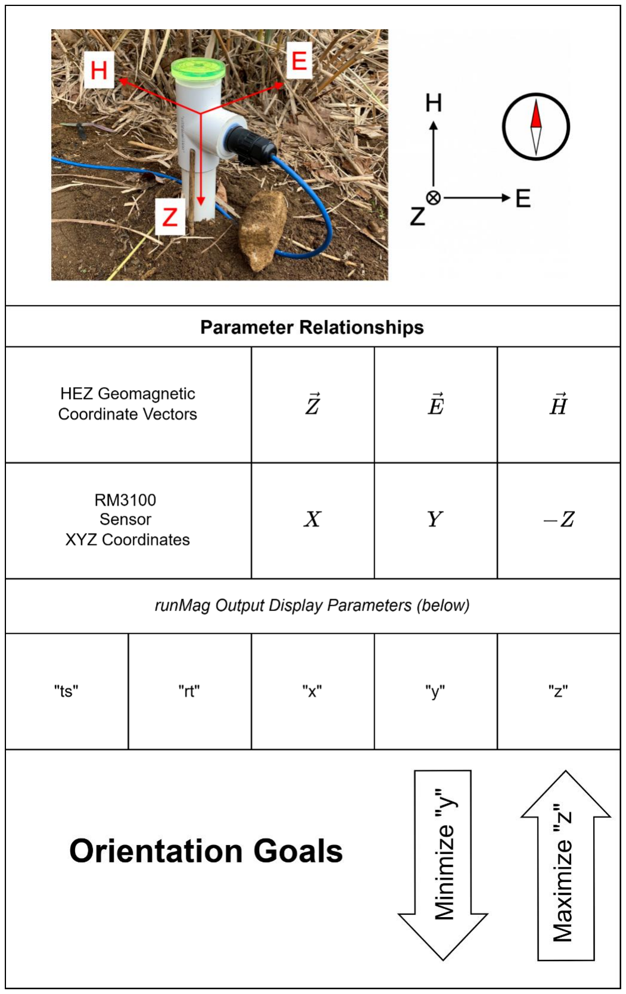
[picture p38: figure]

Figure 23 - Relationship between the various parameters associated with the magnetometer and the displayed data. Orientation is optimized when the "y" values are minimized and the "z" values are maximized.
Orientation requires maximizing the “z” values while minimizing the “y” values. Since the null response from the E vector is easier to discern during the rotation process, observe the “y”-column data while slowly rotating the magnetometer. During rotation, ensure that the unit remains level (per the bubble level indicator on top). Once the lowest absolute value is detected in the “y”-column data, gently compact the soil with a stick. Depending on the type of soil present, pouring about a gallon of water into the hole will make the mud “sticky,” further helping to keep the unit stable during the rotation process.
Once the magnetometer has been oriented and no standing water is present in the hole, scoop the remaining soil into the hole by hand. Gently press the soil with your hands to compact it, but not so hard as to cause the unit to shift from its vertical position. After several days, the soil will again return to its naturally firm state.

## Vegetation Control

Garden weed block fabric was placed around the magnetometer to prevent vegetation growth. A 3ft x 3ft sheet was cut, and an x-cut hole (creating loose flaps) was snipped in the middle of the fabric. The fabric was then placed over the unit and the CAT6 cable connected.
A rubber patio paver was modified to help keep the fabric in place and to further prevent vegetation growth. A spray can (roughly 2-3/4” diameter) was used as a template for the center hole cutout. The hole was cut using an oscillating multi-tool fitted with a narrow blade. To allow the paver to slip into position around the magnetometer housing, a slot was cut from one edge toward the center hole. This is shown in Figure 24 below.

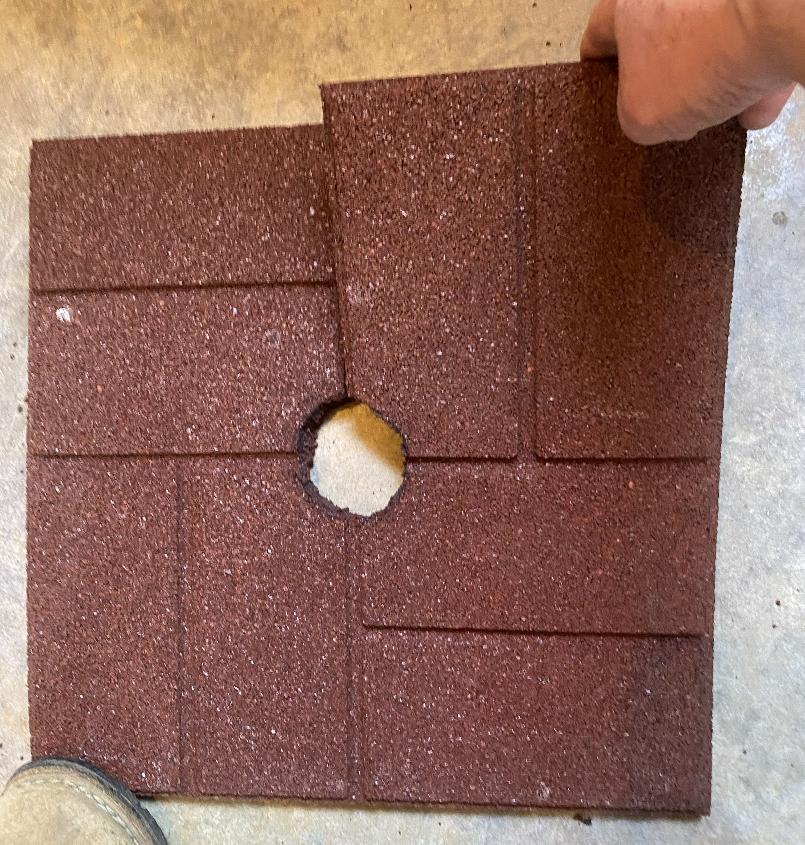
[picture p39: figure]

Figure 24 – The rubber patio paver was modified by cutting a hole in the center and creating a slot on one side.

After installation, the paver was surrounded by 4” x 8” patio bricks. This was done to protect the paver from being damaged by garden tools such as string trimmers. Where the CAT6 cable came up from the ground, a small sheet of landscape fabric was cut and draped around the cable. 4” x 8” bricks were again used to hold the fabric in place and protect the cable. Once everything was in place, the excess fabric was trimmed using scissors.
To delineate the sensor location and prevent damage during lawn care, small wooden fencing was placed around the site. Each fence panel was 3 ft in length. A road reflector was also installed for added visibility. This configuration is shown in Figure 25.

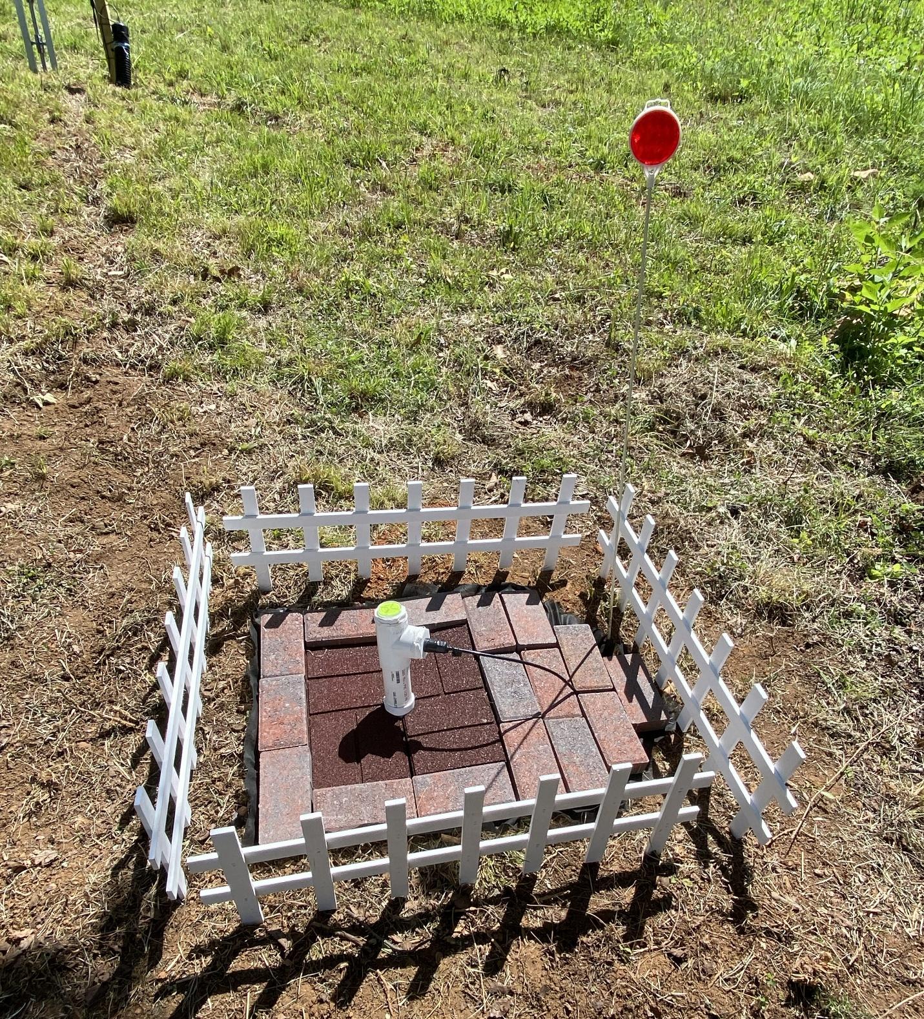
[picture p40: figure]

Figure 25 - The magnetometer installed and properly oriented. The rubber paver and bricks cover the weed block material. The fencing and road reflector increase visibility and prevent accidental damage during lawn care.

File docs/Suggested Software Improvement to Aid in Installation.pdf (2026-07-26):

Mark Braunstein WA4KFZ
26JUN2026

## Suggested Software Improvement to Aid in Installation

The magnetometer is placed in the ground 100ft or more from the Raspberry Pi (located inside the station). For the person in the field installing the magnetometer, there is no convenient way to know if the magnetometer is oriented correctly.
As a suggested improvement to the runMag software, have the internet-connected Raspberry Pi report the XYZ data values to a cloud-based server. Since the Y-data represents the E vector, use the cloud-based server to convert the Y numerical data into an audible tone. Using a cellphone, or other device capable of reaching the internet, connect to a web page and have the tone relayed to the installer’s personal device. While rotating the magnetometer and listening to the tone, the installer would be able to hear the tone pitch change as the unit is rotated to produce the minimum Y value response. At the null condition, the audio tone would be at its lowest pitch, and the E vector would be oriented toward the East. The H vector then, by default, would be oriented to produce the maximum Z value. In this scenario, the installer would only need to ensure that the unit remains level (as indicated by the bubble level) during rotation.

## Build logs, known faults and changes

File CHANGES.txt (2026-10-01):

# CHANGES.txt
===========================================================
# Date: 2026-09-30      # Version 0.0.9: corrected scaling, MQTT TLS verification, CI
#--------------------------------------------------------------------------
- Program the RM3100 cycle-count and NOS registers at sensor init, so the gain
  used for conversion matches the chip (PR #10, fixes #8; thanks @mijahauan).
  Recorded values change: previous releases never programmed these registers
  and divided by a fixed gain of 150.
- Keep the gain exact (0.3671 * CC + 1.5, e.g. 148.34 at CC 400) instead of
  truncating it, which read ~0.23% high at CC 400 and ~1.2% at CC 200
  (PR #20, fixes #14).
- [magnetometer] gain_x/gain_y/gain_z are ignored with a warning; the gain is
  derived from the cycle count. Removed from the sample configs.
- MQTT: verify the broker's TLS certificate, including hostname/IP (PR #11).
  New [mqtt] ca_file setting for self-signed or private-CA brokers (docs: PR #18).
- MQTT: harden the inbound PUBLISH parser; fixes a heap overflow on malformed
  packets (PR #12).
- Docker and macOS support via USB passthrough (PR #4; thanks @ContinuumLS).
- GitHub Actions CI: default and WebSocket builds with gcc and clang,
  warnings as errors, ctest on every PR and push to master (PR #19).
  Fixed the warnings this exposed (prototypes, ignored write() results).
- Known issues: #13, #15, #16, #17; MQTT reconnect and related notes in #7.

===========================================================
# Date: 2026-07-26      # Integrated MQTT capability and updated documentation
#--------------------------------------------------------------------------
- Implemented a custom lightweight MQTT 3.1.1 client with TLS support (OpenSSL).
- Added [mqtt] section to config.toml for broker address, port, credentials, and topic.
- Enabled 1Hz batched data publication of magnetometer and temperature readings.
- Implemented secure configuration broadcast via MQTT (sensitive credentials excluded).
- Added remote command support via MQTT (e.g., 'get_config').
- Created 'mqtt-listener' and 'mqtt-command' testing tools in tools/.
- Updated CMakeLists.txt to handle MQTT build targets and OpenSSL dependencies.
- Updated documentation (README.md, CHANGES.txt, docs/) to acknowledge contributions from Jackson Conti, Michael Hauen, and AI assistants.

===========================================================
# Date: 2026-05-15      # new version to use with pi-eliminator (Pololu Hdw.)
#--------------------------------------------------------------------------
Add Code Review document to RTD sources - try to make it readable.

===========================================================
# Date: 2026-05-14      # new version to use with pi-eliminator (Pololu Hdw.)
#--------------------------------------------------------------------------
Merge Pull Request from Michael Hauen and Claude (Thanks Michael!) to address occasionally dropped sample and other issues and potential issues found in the code.

# Date: 2025-08-19      # new version to use with pi-eliminator (Pololu Hdw.)
#--------------------------------------------------------------------------
Converting Grape2 version to work with any system with USB-2 ports.
I2C calls targeting Pololu i2c rather than Raspberry Pi hardware.

# Date: 2025-05-25      # new version for more general usability
#--------------------------------------------------------------------------
Converting Grape2 version to support Pi5, Orange Pi 5 variants, other variants
I2C calls targeting lgpio rather than pigpio for more general usability.

Further expanding code to run from an event triggered by a rising edge on
the Pi's pin GPIO27 which is the PPS from the system's GNSS device or an RTC.

# Date: 2023-12-18      # git fork for Grape2
#--------------------------------------------------------------------------
Converting I/O to use the Grape main program as the target for I2C calls
targeting pigpio_if2.
Also modifying code to run from a n event triggered by a rising edge on
the Pi's pin GPIO27 which is the PPS from the system's GNSS device.

# Date: 2022-08-8 git tag 0.1.2
#--------------------------------------------------------------------------
Make changes to allow arbitrary values for the Cycle Counts Register.
Make changes to fix old CSV formatting.

# Date: 2022-07-30 git tag 0.1.1
#--------------------------------------------------------------------------
Fix output loop (thanks Bill Engelke!) to make samples much closer to 1 s
Added metadata.json file to the logs file in lieu of a better solution.

# Date: 2021-09-14
#--------------------------------------------------------------------------
Created version 0.1.0

# Date: 2021-08-13 git tag 0.0.17 (alpha, may become 0.1.0)
Added required format string to line ~168 needed to print output file name.
Re-instated the flag that keeps the CSV header from printing in JSON code.

# Date: 2021-08-12 git tag 0.0.17 (alpha, may become 0.1.0)
#--------------------------------------------------------------------------
Changed default Cycle Count value to CC_400.  Changed default Gain value to
GAIN_150.
Changed the measured vector register value to be divided by the A (NOS)
value and saved as a decimal fraction.
Raw values are no longer divided by the -A (NOS) value.
Attempted to adjust formatting of output values to  read consistently in
nano-Tesla rather than micro-Tesla.
Bump version to 0.0.17 (alpha)

# Date: 2021-05-22 git tag 0.0.16
#--------------------------------------------------------------------------
Updating output formatting in JSON mode. Cleaning formatting code a bit.
Bump version to 0.0.16

# Date: 2021-01-17 git tag 0.0.15
#--------------------------------------------------------------------------
Commit some of Dave Larsen's formatting changes. Fix or mess up averaging -
(not sure which)

# Date: 2020-09-20 git tag 0.0.9
#--------------------------------------------------------------------------
Added function i2c_setBitRate() to i2c.c - allow code to specify the I2C
Bus speed at runtime.
Attempting to fix abend due to closing log file when none is in use.

# Date: 2025-10-26  doc overhaul + orientation settings
#--------------------------------------------------------------------------
Documentation refresh across README and docs/:
- New docs: Configuration.md, Orientation-and-Axes.md, Data-Format.md, Limitations.md
- Updated: README.md, Getting-Started.md, Hardware-Setup.md (links), Troubleshooting.md
- Described JSON output schema, units, timestamps, and examples
- Documented [mag_orientation] settings (mag_translate_x/y/z) with allowed values {-180,-90,0,90,180}
- Clarified that 90°-increment rotations are applied to output X/Y/Z per right-hand rule
- Noted config.toml search path (current working directory)

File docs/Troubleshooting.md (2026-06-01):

# Troubleshooting

Common issues and how to resolve them.

## Adapter not found or permission denied
- If you are using an external USB port hub, make certain that it provides the full 5v required by the Pololu adapter. It may require a supplemental power supply to power the device.
- Be certain that the switchon the Pololu device is in the 5v position and that **_both_** the **BLUE** and the **GREEN** LEDs are visible.

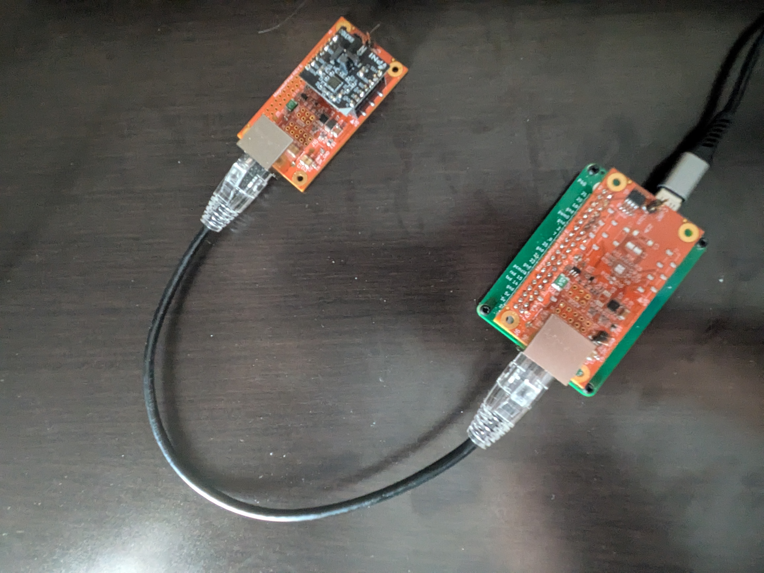
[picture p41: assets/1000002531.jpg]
Adapter LEDs and Switch

*Fig. 5: Pololu adapter LED indicators and 5V switch position.*
- Symptom: `mag-usb -Q` reports errors opening `/dev/ttyACM0`, or EACCES.
- Fixes:
  - Ensure your user is in the dialout (or equivalent) group: `sudo usermod -aG dialout $USER` then re-login.
  - Install udev rule: see docs/Hardware-Setup.md and install/99-PololuI2C.rules.
  - Verify the device node exists: `ls -l /dev/ttyACM*`.
  - Check dmesg: `dmesg | tail -n 50`.

## Wrong device path (ACM1 vs ACM0)
- The ttyACM number can change. Either probe available devices or create a persistent symlink via udev.
- Use `-O /dev/ttyACM<N>` to select the correct device.

## Missing or ignored configuration
- Symptom: `-P` shows defaults instead of your values.
- Causes and fixes:
  - `config.toml` is not in the current working directory. Run from the folder containing `config.toml`, or pass an absolute path (feature not currently implemented; current build only checks CWD).
  - Syntax errors: ensure `key = value` format, quoted strings, and whole-line comments only (no inline comments).

## Invalid orientation values
- Symptom: Orientation prints as `0, 0, 0` or axis swaps don’t match expectations.
- Notes:
  - Allowed values are only `-180, -90, 0, 90, 180`. Any other value is treated as `0`.
  - Rotations are applied in order X → Y → Z using the right-hand rule. See docs/Orientation-and-Axes.md for examples.

## Build fails
- Ensure CMake 3.22+ and a recent GCC/Clang.
- Try a clean build directory.
- If errors are warnings-as-errors, you can temporarily disable `-DENABLE_WERROR=ON`.

## Tests fail
- Some tests interact with the i2c-pololu logic; ensure the adapter is not locked by another process.
- Re-run with verbose CTest: `(cd build && ctest -VV)`.

## No data from sensor
- Check wiring (SDA/SCL/GND, optional 5V).

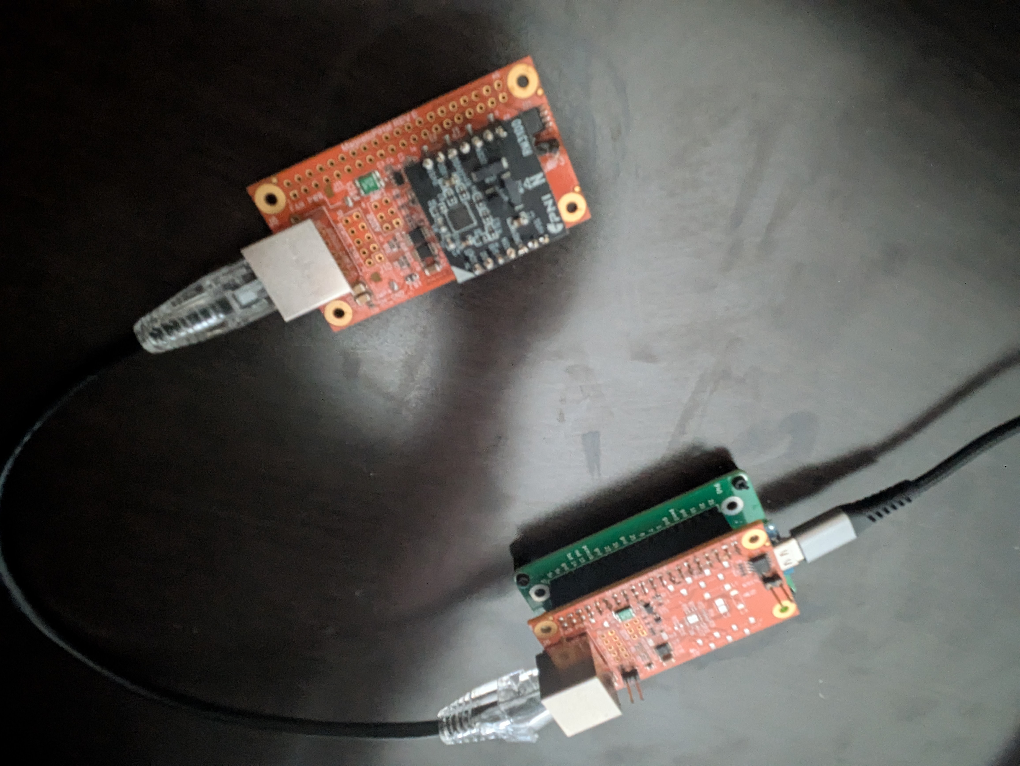
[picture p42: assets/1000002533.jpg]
Wiring Connections Troubleshooting

*Fig. 6: Verifying sensor wiring connections.*
- Confirm pull-up resistors present.
- Verify device addresses match expected values in config (MCP9808/Magnetometer addresses).
- Use diagnostics:
  - `-Q` to verify the Pololu adapter.
  - `-S` to scan the I²C bus.
  - `-M` to verify the magnetometer.
  - `-T` to verify the temperature sensor.

## Interleaved JSON and logs
- If you require a clean JSON stream, redirect  (`2>/dev/null`) or filter lines that do not start with `{`.

## Getting more help
- Open an issue with logs:
  - Your distro and kernel version
  - Output of `lsusb`, `dmesg` after plugging the adapter
  - mag-usb CLI, version, and full console output

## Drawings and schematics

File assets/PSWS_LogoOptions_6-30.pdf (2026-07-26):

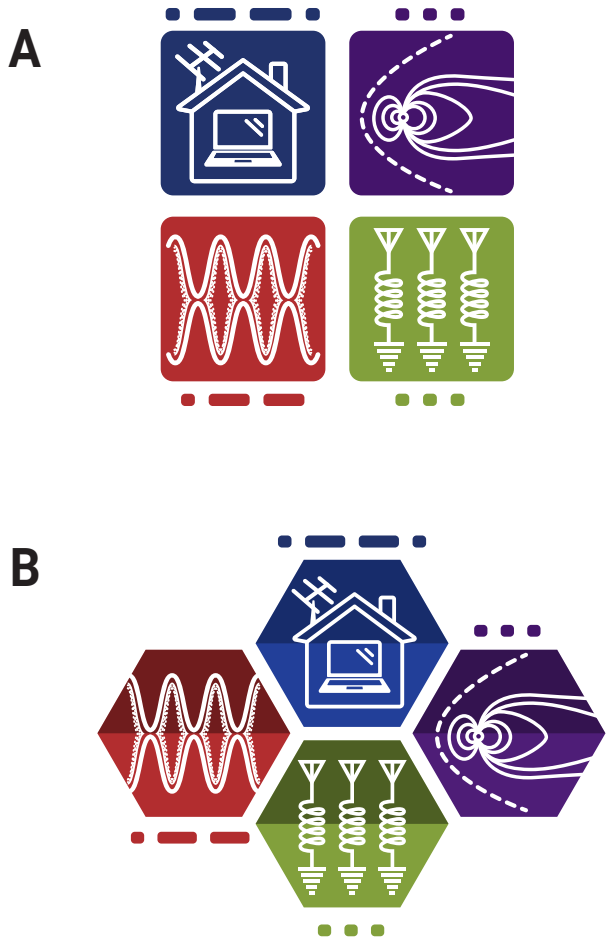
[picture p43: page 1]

S

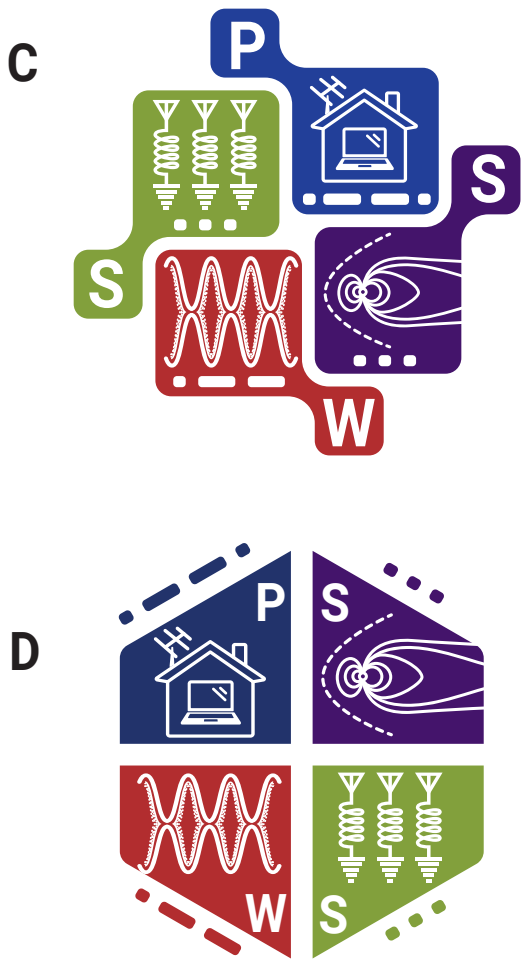
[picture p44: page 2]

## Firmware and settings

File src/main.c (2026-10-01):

//=========================================================================
// main.c
//
// A command line interface for the RM3100 3-axis magnetometer from PNI Sensor Corp.
//
// Author:      David Witten, KD0EAG
// Date:        December 18, 2025
// License:     GPL 3.0
//=========================================================================
#include <fcntl.h>
#include <sys/stat.h>
#include <errno.h>
#include <unistd.h>
#include <linux/limits.h>
#include "main.h"
#include "rm3100.h"
#include "i2c.h"
#include "cmdmgr.h"
#include "config.h"
#include "sensor_tests.h"
#include "i2c-pololu.h"
#ifdef USE_WEBSOCKET
#include "ws_bridge.h"
#endif
#include "mqtt_client.h"

#include <pthread.h>
#include <signal.h>
#include <unistd.h>
#include <time.h>

//------------------------------------------
// Static and Global variables
//------------------------------------------
char Version[32];
int volatile killflag;
static char outBuf[256];
// Prototypes for local helpers
static double mcp9808_decode_celsius(uint8_t msb, uint8_t lsb);
static int mqtt_init_client(pList *p);
static void mqtt_cleanup_client(pList *p);
static void publish_config_msg(pList *p);
// Default device path matches install/99-PololuI2C.rules, which symlinks
// any Pololu USB-to-I2C adapter (PID 0x2502 or 0x2503) to /dev/ttyMAG0.
// Use -O /dev/ttyACMn to override when the udev rule is not installed.
char portpath[PATH_MAX] = "/dev/ttyMAG0";

#ifdef USE_PIPES
     char fifoCtrl[] = "/run/mag-usb/magctl.fifo";
     char fifoData[] = "/run/mag-usb/magdata.fifo";
     char fifoHome[] = "/run/mag-usb";
     // int PIPEIN  = -1;
     // int PIPEOUT = -1;
#endif //USE_PIPES

#if((USE_LGPIO || USE_RGPIO) && USE_WAITFOREDGE)
#define PPS_GPIO_PIN    27
#define PPS_TIMEOUTSECS 2.0
void cbTestFunc()
{
    printf("Got Callback!/n");
}

int wait_for_edge(int sbc, int handle, int gpio_pin, int edge, CBFunc_t f, int timeout)
{
    int rv = 0;
    rv = callback(sbc, handle, gpio_pin, edge, f, NULL);
    return rv;
}
int rc = 0;
// wait_for_edge((int)1, (int)1, PPS_GPIO_PIN, RISING_EDGE, cbTestFunc, PPS_TIMEOUTSECS);
#endif

//---------------------------------------------------------------
// Shared state between threads
//---------------------------------------------------------------
volatile sig_atomic_t shutdown_requested = 0;   // Signal-safe flag
pthread_mutex_t data_mutex = PTHREAD_MUTEX_INITIALIZER; // Protect shared data
int sensor_data = 0;                            // Simulated sensor data

//---------------------------------------------------------------
//  main()
//---------------------------------------------------------------
int main(int argc, char** argv)
{
    pList   ctl;
    pList   *p = &ctl;
    int     rv = 0;

#if(USE_POLOLU)
    i2c_pololu_adapter pAdapter;
#endif

    //-----------------------------------------
    //  Setup magnetometer parameter defaults.
    //-----------------------------------------
    memset(p, 0, sizeof(pList));
    setProgramDefaults(p);
#if(USE_POLOLU)
    p->use_I2C_converter    = 1;
    p->adapter              = &pAdapter;
#else
    p->i2cBusNumber         = RASPI_I2C_BUS1;
#endif

    //-----------------------------------------
    //  Load configuration from TOML file
    //  (command line args will override these)
    //-----------------------------------------
    const char *etc_config = "/etc/mag-usb/config.toml";
    const char *local_config = "config.toml";
    const char *custom_config = NULL;

    // Check for -f flag manually before getCommandLine()
    for (int i = 1; i < argc; i++) {
        if (strcmp(argv[i], "-f") == 0 && (i + 1) < argc) {
            custom_config = argv[i+1];
            break;
        }
    }

    if (custom_config) {
        load_config(custom_config, p);
    } else {
        if (load_config(etc_config, p) != 0) {
            // If /etc config failed or didn't exist, try local directory
            load_config(local_config, p);
        }
    }

    if((rv = getCommandLine(argc, argv, p)) != 0)
    {
        return rv;
    }

    // If user requested to only show settings, print and exit before hardware init
    if(p->showSettingsOnly)
    {
        showSettings(p);
        
        // PR-5: also read back chip state if possible
        if (i2c_init(p) == 0) {
            if (i2c_pololu_check_device_available(p->portpath, 100) == 0 &&
                i2c_pololu_is_device_valid(p->portpath) == 0 &&
                i2c_open(p) >= 0) 
            {
                // Ensure registers are set before reading back, or just read back what's there?
                // The requirement is to correct initialization order.
                readCycleCountRegs(p);
                i2c_close(p);
            }
        }

        free_config_strings(p);
        if(p->pipeInFd >= 0)
        {
            close(p->pipeInFd);
        }
        if(p->pipeOutFd >= 0)
        {
            close(p->pipeOutFd);
        }
        printf("Program terminated.\n");
        exit(0);
    }

    if(p->usePipes)
    {
        setupPipes(p);
    }

    if(p->mqtt_enable)
    {
        if(mqtt_init_client(p) != 0)
        {
            fprintf(OUTPUT_ERROR, "MQTT init failed. Continuing without MQTT.\n");
        }
    }

#ifdef USE_WEBSOCKET
    if(p->useWebSocket)
    {
        if(!ws_server_init(p->webSocketBindAddr, (uint16_t)p->webSocketPort))
        {
            fprintf(OUTPUT_ERROR, "WebSocket init failed: %s\n", ws_server_last_error());
            if(p->pipeInFd >= 0)
            {
                close(p->pipeInFd);
            }
            if(p->pipeOutFd >= 0)
            {
                close(p->pipeOutFd);
            }
            free_config_strings(p);
            exit(1);
        }
    }
#endif

    if(i2c_init(p))
    {
        fprintf(OUTPUT_ERROR, "Unable to initialize I2C Adaptor handle.\n");
        exit(1);
    }
    rv = i2c_pololu_check_device_available(p->portpath, 1000);
    if(rv == 0)
    {
        // Validate the device is the expected Pololu adapter
        rv = i2c_pololu_is_device_valid(p->portpath);
        if(rv != 0)
        {
            fprintf(OUTPUT_ERROR, "Unsupported or invalid Pololu adapter at %s (error %d). Exiting...\n", p->portpath, rv);
            exit(1);
        }
        if((rv = i2c_open(p)) < 0)
        {
            fprintf(OUTPUT_ERROR, "Failed to open I2C port '%s'. Exiting...\n", p->portpath);
            exit(1);
        }
    }
    else
    {
        fprintf(OUTPUT_ERROR, "I2C adapter device '%s' not available (error %d). Exiting...\n", p->portpath, rv);
        exit(1);
    }

#if(USE_POLOLU)
    if(p->checkPololuAdaptor)
    {
        if(i2c_verifyPololuAdaptor(p))
        {
            fprintf(OUTPUT_PRINT, "  Pololu Adapter OK.\n");
        }
        else
        {
            fprintf(OUTPUT_PRINT, "  Pololu Adapter NOT so OK.\n");
            // return -1;
            exit(1);
        }
        exit(0);
}

    //-----------------------------------------------------
    // Get interface info and scan for i2c devices.
    //-----------------------------------------------------
    if(p->scanI2CBUS)
    {
        if(i2c_scanForBusDevices(p) <= 0)
        {
            exit(1);
            //return -1;
        }
        exit(0);
    }
#endif

    //-----------------------------------------------------
    // Verify the Temp sensor presence and Version.
    //-----------------------------------------------------
    if(p->checkTempSensor)
    {
        if(!i2c_verifyTempSensor(p))
        {
            fprintf(OUTPUT_PRINT, "  Temp Sensor OK.\n");
         }
        else
        {
            fprintf(OUTPUT_PRINT, "  Temp Sensor NOT so OK.\n");
            return 1;
        }
        exit(0);
    }

    //-----------------------------------------
    // Verify the Mag sensor presence and Version.
    //-----------------------------------------
    if(p->checkMagSensor)
    {
        if(i2c_verifyMagSensor(p))
        {
            fprintf(OUTPUT_ERROR, "Unable to Verify the magnetometer.\n");
            exit(1);
        }
        exit(0);
    }

    //-----------------------------------------
    //  Initialize the Mag sensor registers.
    //-----------------------------------------
    i2c_initMagSensor(p);

    //-----------------------------------------------------
    //  Main program loop.
    //-----------------------------------------------------
#if(USE_PTHREADS)
    pthread_t sensor_thread, print_thread, signal_thread;
    fprintf(OUTPUT_PRINT, "\n");

    // Block SIGHUP/SIGABRT/SIGINT in the calling thread *before* any
    // pthread_create.  Newly created threads inherit this mask, so
    // these signals are blocked in every thread except the dedicated
    // signal_handler thread that calls sigwait().  Without this, the
    // kernel delivers an arriving signal to whichever thread does not
    // have it masked -- typically the print or sensor thread -- where
    // there is no handler, so the process terminates instead of going
    // through the graceful shutdown_requested path.
    {
        sigset_t blocked;
        sigemptyset(&blocked);
        sigaddset(&blocked, SIGHUP);
        sigaddset(&blocked, SIGABRT);
        sigaddset(&blocked, SIGINT);
        if (pthread_sigmask(SIG_BLOCK, &blocked, NULL) != 0)
        {
            perror("pthread_sigmask(SIG_BLOCK)");
            exit(1);
        }
    }

    // Create threads
    if (pthread_create(&sensor_thread, NULL, read_sensors, (void *) p) != 0)
    {
        perror("pthread_create sensor");
        exit(1);
    }
    if (pthread_create(&print_thread, NULL, print_data, (void *) p) != 0)
    {
        perror("pthread_create print");
        exit(1);
    }
    if (pthread_create(&signal_thread, NULL, signal_handler_thread, NULL) != 0)
    {
        perror("pthread_create signal");
        exit(1);
    }
    // Wait for signal handler thread to complete (it will only return on signal)
    pthread_join(signal_thread, NULL);
    // Signal handler has set shutdown_requested, so wait for other threads to finish
    pthread_join(sensor_thread, NULL);
    pthread_join(print_thread, NULL);
    // Clean up
    pthread_mutex_destroy(&data_mutex);
#else

    while(1)
    {
        // if(PPS_Flag)
        // {
        //     PPS_Flag = 0;
        //     //formatOutput(p, outBuf);
        //     formatOutput(p);
        //     fflush(outfp);
        // }
#if(USE_WAITFOREDGE)
        if(!(rv = wait_for_edge(p->po, (unsigned) PPS_GPIO_PIN, RISING_EDGE, PPS_TIMEOUTSECS)))
        {
            utcTime = getUTC();
            strftime(utcStr, UTCBUFLEN, "%d %b %Y %T", utcTime);                // RFC 2822: "%a, %d %b %Y %T %z"      RFC 822: "%a, %d %b %y %T %z"
    #if(CONSOLE_OUTPUT)
            fprintf(OUTPUT_PRINT, "   [CHILD]: {ts: \"%s\", lastStatus: \"Missed PPS Timeout!\"}", utcStr);
            fflush(OUTPUT_PRINT);
    #else
            char outstr[MAXPATHBUFLEN] = "";
            sprintf(outstr, "   [CHILD]: {ts: \"%s\", lastStatus: \"Missed PPS Timeout!\"}", utcStr);
            write(PIPEOUT, outstr);
    #endif
            // Set exit return value.
            rv = 2;
            break;
        }
#endif
#if __DEBUG
        else
        {
            fputs(".", OUTPUT_PRINT);
            fflush(OUTPUT_PRINT);
        }
#endif
    }
    //-----------------------------------------------------
    //  Cleanup Callback, PIGPIO, and exit.
    //-----------------------------------------------------
    #if(USE_RGPIO || USE_LGPIO)
        rv = callback_cancel(p->edge_cb_id);
    #elif (USE_PIGPIO)
        rv = event_callback_cancel(p->edge_cb_id);
    #endif
#endif // USE_PTHREADS
    // Free any allocated config strings before exit
    if(p->pipeInFd >= 0) close(p->pipeInFd);
    if(p->pipeOutFd >= 0) close(p->pipeOutFd);
#ifdef USE_WEBSOCKET
    ws_server_shutdown();
#endif
    mqtt_cleanup_client(p);
    free_config_strings(p);
    printf("Program terminated.\n");
    return 0;
}

// Prototypes for local helpers
static double mcp9808_decode_celsius(uint8_t msb, uint8_t lsb);
static int mqtt_init_client(pList *p);
static void mqtt_cleanup_client(pList *p);
static void publish_config_msg(pList *p);

//---------------------------------------------------------------
// MQTT Helpers
//---------------------------------------------------------------
static void publish_config_msg(pList *p) {
    if (!p->mqtt || !mqtt_client_is_connected(p->mqtt)) return;

    char buf[1024];
    // Create a JSON config message, explicitly omitting the password
    snprintf(buf, sizeof(buf), 
        "{ \"msg_type\": \"config\", \"version\": \"%s\", \"mqtt\": { \"broker\": \"%s\", \"port\": %d, \"topic\": \"%s\", \"client_id\": \"%s\", \"use_tls\": %s }, "
        "\"mag\": { \"address\": \"0x%02X\", \"cc\": [%d, %d, %d], \"gain\": [%.4f, %.4f, %.4f], \"rate\": \"0x%02x\", \"nos\": %d }, "
        "\"location\": { \"lat\": \"%s\", \"lon\": \"%s\", \"alt\": \"%s\", \"grid\": \"%s\" } }",
        p->Version ? p->Version : "unknown",
        p->mqtt_broker_address ? p->mqtt_broker_address : "null",
        p->mqtt_broker_port,
        p->mqtt_topic ? p->mqtt_topic : "null",
        p->mqtt_client_id ? p->mqtt_client_id : "null",
        p->mqtt_use_tls ? "true" : "false",
        p->magAddr, p->cc_x, p->cc_y, p->cc_z, p->x_gain, p->y_gain, p->z_gain, p->TMRCRate, p->NOSRegValue,
        p->latitude ? p->latitude : "", p->longitude ? p->longitude : "", p->elevation ? p->elevation : "", p->grid_square ? p->grid_square : ""
    );

    mqtt_client_publish(p->mqtt, p->mqtt_topic, buf, strlen(buf));
}

static void mqtt_msg_handler(void *user_data, const char *topic, const char *payload, size_t payload_len) {
    pList *p = (pList *)user_data;
    
    // Create a null-terminated copy of the payload for string functions
    char *payload_str = (char *)malloc(payload_len + 1);
    if (!payload_str) return;
    memcpy(payload_str, payload, payload_len);
    payload_str[payload_len] = '\0';

    // Check if it's a command on the command topic
    char cmd_topic[256];
    snprintf(cmd_topic, sizeof(cmd_topic), "%s/command", p->mqtt_topic);

    if (strcmp(topic, cmd_topic) == 0) {
        if (strstr(payload_str, "get_config")) {
            publish_config_msg(p);
        }
    }
    free(payload_str);
}

static int mqtt_init_client(pList *p) {
    if (!p->mqtt_enable) return 0;

    p->mqtt = mqtt_client_new();
    if (!p->mqtt) return -1;

    mqtt_client_set_callback(p->mqtt, mqtt_msg_handler, p);
    mqtt_client_set_ca_file(p->mqtt, p->mqtt_ca_file);

    if (mqtt_client_connect(p->mqtt, p->mqtt_broker_address, p->mqtt_broker_port, p->mqtt_use_tls) != 0) {
        fprintf(OUTPUT_ERROR, "MQTT connection failed to %s:%d\n", p->mqtt_broker_address, p->mqtt_broker_port);
        return -1;
    }

    if (mqtt_client_authenticate(p->mqtt, p->mqtt_username, p->mqtt_password, p->mqtt_client_id) != 0) {
        fprintf(OUTPUT_ERROR, "MQTT authentication failed for client %s\n", p->mqtt_client_id);
        return -1;
    }

    // Subscribe to command topic for configuration requests
    char cmd_topic[256];
    snprintf(cmd_topic, sizeof(cmd_topic), "%s/command", p->mqtt_topic);
    mqtt_client_subscribe(p->mqtt, cmd_topic);

    // Initial config publication
    publish_config_msg(p);

    return 0;
}

static void mqtt_cleanup_client(pList *p) {
    if (p->mqtt) {
        mqtt_client_free(p->mqtt);
        p->mqtt = NULL;
    }
}

//---------------------------------------------------------------
// Function to simulate reading sensor data
//---------------------------------------------------------------
void* read_sensors(void* arg)
{
    (void)arg;
    while (!shutdown_requested)
    {
        // Sleep for 1000 ms (1 second)
        usleep(1000000);

        // Check for shutdown request
        if (shutdown_requested)
        {
            break;
        }
    }
    return NULL;
}

//---------------------------------------------------------------
// Function to print sensor data once per UTC second.
//
// The cadence is anchored at the next whole CLOCK_REALTIME second
// and advanced by exactly +1 s each iteration, using
// clock_nanosleep() with TIMER_ABSTIME so the wakeup is aligned to
// the wall clock rather than relative to whenever the previous
// formatOutput() call finished.
//
// The previous implementation (nanosleep(1 s) after each read) drifted
// by however long the synchronous I2C POLL + DRDY + 9-byte XYZ read
// + MCP9808 temp read took, and once accumulated drift exceeded one
// second the corresponding tick was silently skipped — the
// "occasional missed sample" Dave Witten reports against the
// pre-rewrite code path.  Aligning to an absolute deadline removes
// both the drift and the silent skip; the loop also explicitly
// detects and logs a missed sample whenever formatOutput overruns,
// so the operator can see *why* a tick disappeared instead of just
// noticing a gap after the fact.
//---------------------------------------------------------------
void* print_data(void* arg)
{
    pList * p = (pList *) arg;

    // Anchor on the next whole UTC second.
    struct timespec deadline;
    clock_gettime(CLOCK_REALTIME, &deadline);
    deadline.tv_sec  += 1;
    deadline.tv_nsec  = 0;

    while (!shutdown_requested)
    {
#ifdef USE_WEBSOCKET
        if (p->useWebSocket)
        {
            ws_server_poll();
        }
#endif

        // Sleep until the absolute deadline.  Retry on EINTR so a
        // stray signal does not cost us a sample; honour shutdown
        // between retries so SIGTERM still exits promptly.
        int rc;
        do
        {
            rc = clock_nanosleep(CLOCK_REALTIME, TIMER_ABSTIME, &deadline, NULL);
        } while (rc == EINTR && !shutdown_requested);

        if (shutdown_requested)
        {
            break;
        }
        if (rc != 0)
        {
            fprintf(OUTPUT_ERROR,
                    "clock_nanosleep(CLOCK_REALTIME, TIMER_ABSTIME) failed: %d\n",
                    rc);
            break;
        }

        formatOutput(p);

        if (p->mqtt_enable && p->mqtt)
        {
            mqtt_client_poll(p->mqtt);
        }

        // Advance to the next tick.  If formatOutput overran by one
        // or more whole seconds, skip-advance and log each missed
        // tick so an operator can correlate gaps with their causes
        // (slow I2C reads, scheduler preemption, clock steps, etc.).
        deadline.tv_sec += 1;

        struct timespec now;
        clock_gettime(CLOCK_REALTIME, &now);
        while (now.tv_sec  > deadline.tv_sec ||
              (now.tv_sec == deadline.tv_sec && now.tv_nsec > deadline.tv_nsec))
        {
            fprintf(OUTPUT_ERROR,
                    "{ \"lastStatus\": \"missed_sample\", \"deadline\": %ld.%09ld }\n",
                    (long)deadline.tv_sec, (long)deadline.tv_nsec);
            fflush(OUTPUT_ERROR);
            deadline.tv_sec += 1;
        }
    }
    return NULL;
}

//---------------------------------------------------------------
// Signal handler thread function
//---------------------------------------------------------------
void* signal_handler_thread(void* arg)
{
    (void)arg;
    sigset_t sigset;
    int signum;

    // Block SIGHUP, SIGABRT, and SIGINT in this thread
    sigemptyset(&sigset);
    sigaddset(&sigset, SIGHUP);
    sigaddset(&sigset, SIGABRT);
    sigaddset(&sigset, SIGINT);
    pthread_sigmask(SIG_BLOCK, &sigset, NULL);

    // Wait for any of the blocked signals
    while (1)
    {
        if (sigwait(&sigset, &signum) == 0)
        {
            switch (signum)
            {
                case SIGHUP:
                    printf("Received SIGHUP. Shutting down gracefully.\n");
                    break;
                case SIGABRT:
                    printf("Received SIGABRT. Shutting down gracefully.\n");
                    break;
                case SIGINT:
                    printf("Received SIGINT. Shutting down gracefully.\n");
                    break;
                default:
                    printf("Received unexpected signal %d.\n", signum);
                    break;
            }
            // Set shutdown flag
            shutdown_requested = 1;
            break;
        }
    }
    return NULL;
}

//---------------------------------------------------------------
// formatOutput(volatile pList *p)
//---------------------------------------------------------------
static int norm_angle(int a)
{
    if(a == 180 || a == -180) return 180;
    if(a == 90 || a == -90 || a == 0) return a;
    return 0;
}

//---------------------------------------------------------------
// apply_orientation(volatile pList *p)
//---------------------------------------------------------------
static void apply_orientation(const pList *p, double *x, double *y, double *z)
{
    double X = *x, Y = *y, Z = *z;
    int ax = norm_angle(p->mag_translate_x);
    int ay = norm_angle(p->mag_translate_y);
    int az = norm_angle(p->mag_translate_z);

    // Rotate around X axis (affects Y,Z)
    if(ax == 90)
    {
        double newY = -Z;
        double newZ =  Y;
        Y = newY; Z = newZ;
    }
    else if(ax == -90)
    {
        double newY =  Z;
        double newZ = -Y;
        Y = newY; Z = newZ;
    }
    else if(ax == 180)
    {
        Y = -Y; Z = -Z;
    }

    // Rotate around Y axis (affects X,Z)
    if(ay == 90)
    {
        double newX =  Z;
        double newZ = -X;
        X = newX; Z = newZ;
    }
    else if(ay == -90)
    {
        double newX = -Z;
        double newZ =  X;
        X = newX; Z = newZ;
    }
    else if(ay == 180)
    {
        X = -X; Z = -Z;
    }

    // Rotate around Z axis (affects X,Y)
    if(az == 90)
    {
        double newX = -Y;
        double newY =  X;
        X = newX; Y = newY;
    }
    else if(az == -90)
    {
        double newX =  Y;
        double newY = -X;
        X = newX; Y = newY;
    }
    else if(az == 180)
    {
        X = -X; Y = -Y;
    }

    *x = X; *y = Y; *z = Z;
}
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

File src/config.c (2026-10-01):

//=========================================================================
// config.c
//
// Simple TOML configuration parser implementation
//=========================================================================
#include "config.h"
#include "main.h"
#include <stdio.h>
#include <stdlib.h>
#include <string.h>
#include <ctype.h>
#include <errno.h>
#include <limits.h>

#define MAX_LINE_LENGTH 512
#define MAX_KEY_LENGTH 64
#define MAX_VALUE_LENGTH 256

//---------------------------------------------------------------
// Helper: Trim leading and trailing whitespace
//---------------------------------------------------------------
static char *trim_whitespace(char *str)
{
    char *end;

    // Trim leading space
    while(isspace((unsigned char)*str))
    {
        str++;
    }
    if(*str == 0)
    {
        return str;
    }
    // Trim trailing space
    end = str + strlen(str) - 1;
    while(end > str && isspace((unsigned char)*end))
    {
        end--;
    }
    end[1] = '\0';
    return str;
}

//---------------------------------------------------------------
// Helper: Remove quotes from string value
//---------------------------------------------------------------
static char *remove_quotes(char *str)
{
    size_t len = strlen(str);
    if(len >= 2 && str[0] == '"' && str[len-1] == '"')
    {
        str[len-1] = '\0';
        return str + 1;
    }
    return str;
}

//---------------------------------------------------------------
// Helper: Parse boolean value (true/false)
//---------------------------------------------------------------
static int parse_bool(const char *value)
{
    if(strcmp(value, "true") == 0) return TRUE;
    if(strcmp(value, "false") == 0) return FALSE;
    return atoi(value) != 0;
}

//---------------------------------------------------------------
// Helper: Parse integer with support for hex (0x) format
//---------------------------------------------------------------
static int parse_int(const char *value)
{
    return (int)strtol(value, NULL, 0);
}

//---------------------------------------------------------------
// Helper: Check if line is a section header [section]
//---------------------------------------------------------------
static int is_section_header(const char *line, char *section_name)
{
    const char *ptr = line;

    // Skip whitespace
    while(isspace((unsigned char)*ptr))
    {
        ptr++;
    }
    if(*ptr != '[')
    {
        return 0;
    }
    ptr++;

    // Extract section name
    int i = 0;
    while(*ptr && *ptr != ']' && i < MAX_KEY_LENGTH - 1)
    {
        section_name[i++] = *ptr++;
    }
    section_name[i] = '\0';

    // Trim section name
    char *trimmed = trim_whitespace(section_name);
    if(trimmed != section_name)
    {
        memmove(section_name, trimmed, strlen(trimmed) + 1);
    }
    return (*ptr == ']');
}

//---------------------------------------------------------------
// Helper: Parse key = value line
//---------------------------------------------------------------
static int parse_key_value(const char *line, char *key, char *value)
{
    const char *equals = strchr(line, '=');
    if(!equals)
    {
        return 0;
    }
    // Extract key
    size_t key_len = equals - line;
    if(key_len >= MAX_KEY_LENGTH)
    {
        key_len = MAX_KEY_LENGTH - 1;
    }
    memcpy(key, line, key_len);
    key[key_len] = '\0';

    // Extract value
    snprintf(value, MAX_VALUE_LENGTH, "%s", equals + 1);

    // Trim both
    char *trimmed_key = trim_whitespace(key);
    char *trimmed_value = trim_whitespace(value);
    if(trimmed_key != key)
    {
        memmove(key, trimmed_key, strlen(trimmed_key) + 1);
    }
    if(trimmed_value != value)
    {
        memmove(value, trimmed_value, strlen(trimmed_value) + 1);
    }
    // Remove quotes from value
    trimmed_value = remove_quotes(value);
    if(trimmed_value != value)
    {
        memmove(value, trimmed_value, strlen(trimmed_value) + 1);
    }
    return 1;
}
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

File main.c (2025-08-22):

//=========================================================================
// main.c
//
// A command line interface for the RM3100 3-axis magnetometer from PNI Sensor Corp.
//
// Author:      David Witten, KD0EAG
// Date:        December 18, 2023
// License:     GPL 3.0
// Note:        replaces i2c.c (using file system calls to read(), write(), etc.
//              with calls to pigpio. 
//              Also adding callbacks on GPIO27 for PPS rising edge.
//=========================================================================
#include "main.h"
//#include <inttypes.h>
#include "src/i2c_pololu.h"
#include "src/cmdmgr.h"

//------------------------------------------
// Debugging output
//------------------------------------------
// see main.h
//
//#define _DEBUG          FALSE
//#define CONSOLE_OUTPUT  TRUE
//#define USE_WAITFOREDGE TRUE

//------------------------------------------
// Macros
//------------------------------------------
#define PPS_GPIO_PIN    27
#define PPS_TIMEOUTSECS 2.0

//------------------------------------------
// Static and Global variables
//------------------------------------------
int volatile PPS_Flag   = 0;
int volatile killflag   = 0;
char   Version[32]      = MAGDATA_VERSION;
static char outBuf[256] = "";

char fifoCtrl[] = "/home/pi/PSWS/Sstat/magctl.fifo";
char fifoData[] = "/home/pi/PSWS/Sstat/magdata.fifo";
char fifoHome[] = "/run/user/";
// char fifoCtrl[PATH_MAX] = "";
// char fifoData[PATH_MAX] = "";
// sprintf(fifoCtrl, "%s%d%s", fifoHome, getuid(), "/magctl.fifo");
// sprintf(fifoData, "%s%d%s", fifoHome, getuid(), "/magdata.fifo");
int PIPEIN  = -1;
int PIPEOUT = -1;

#if((USE_LGPIO || USE_RGPIO) && USE_WAITFOREDGE)

void cbTestFunc()
{
    printf("Got Callback!/n");
}

int wait_for_edge(int sbc, int handle, int gpio_pin, int edge, CBFunc_t f, int timeout)
{
    int rv = 0;
    rv = callback(sbc, handle, gpio_pin, edge, f, NULL);
    return rv;
}

int rc = 0;
// wait_for_edge((int)1, (int)1, PPS_GPIO_PIN, RISING_EDGE, cbTestFunc, PPS_TIMEOUTSECS);

#endif

//---------------------------------------------------------------
//  main()
//---------------------------------------------------------------
int main(int argc, char** argv)
{
    pList   ctl;
    pList   *p = &ctl;
    int     rv = 0;
    FILE    *outfp = (FILE *)stdout;
    char    utcStr[UTCBUFLEN] = "";
    struct  tm *utcTime = getUTC();

#if(_DEBUG)
    #if(USE_PIPES)
        printf("fifoCtrl: %s\n", fifoCtrl);
        printf("fifoData: %s\n", fifoData);
    #endif
    fprintf(OUTPUT_PRINT, "\n[CHILD] In %s child process.\n", argv[0]);
    fflush(stdout);
#endif

    //-----------------------------------------
    //  Setup magnetometer parameter defaults.
    //-----------------------------------------
    if(p != NULL)
    {
        memset(p, 0, sizeof(pList));
    }

    //p->po               = 0;
    p->adapter          = (pololu_i2c_adapter *) NULL;
    p->ppsHandle        = 0;
    p->magHandle        = 0;
    p->localTempHandle  = 0;
    p->remoteTempHandle = 0;
    p->doBistMask       = 0;
    p->cc_x             = CC_400;
    p->cc_y             = CC_400;
    p->cc_z             = CC_400;
    p->x_gain           = GAIN_150;
    p->y_gain           = GAIN_150;
    p->z_gain           = GAIN_150;
    p->tsMilliseconds   = 0;
    p->TMRCRate         = 0x96;
    p->Version          = Version;
    p->samplingMode     = POLL;
    p->readBackCCRegs   = FALSE;
    p->CMMSampleRate    = 400;
    p->NOSRegValue      = 60;
    p->DRDYdelay        = 10;
    p->magRevId         = 0x0;
    p->i2cBusNumber     = RASPI_I2C_BUS1;
    p->remoteTempAddr   = MCP9808_RMT_I2CADDR_DEFAULT;
    p->magnetometerAddr = RM3100_I2C_ADDRESS;
    p->usePipes         = USE_PIPES;
    p->pipeInPath       = fifoCtrl;
    p->pipeOutPath      = fifoData;
    p->readBackCCRegs   = FALSE;

//    if((rv = getCommandLine(argc, argv, p)) != 0)
//    {
//        return rv;
//    }

#if(USE_PIPES)
    //-----------------------------------------
    //  Setup the I/O pipes
    //-----------------------------------------
    int  fdPipeIn;
    int  fdPipeOut;

    if(p->usePipes == TRUE)
    {
        // Notice that fdPipeOut and fdPipeIn are intentionally reversed.
        if(!(fdPipeOut = open(p->pipeInPath, O_WRONLY | O_CREAT)))
        {
            perror("    [CHILD] Open PIPE Out failed: ");
            fprintf(OUTPUT_PRINT, "%s", p->pipeInPath);
            exit(1);
        }
        else
        {
            fprintf(OUTPUT_PRINT, "    [CHILD] Open PIPE Out OK.\n");
            fflush(OUTPUT_PRINT);
            PIPEOUT = fdPipeOut;
        }

        if(!(fdPipeIn = open(p->pipeOutPath, O_RDONLY | O_CREAT)))
        {    
            perror("    [CHILD] Open PIPE In failed: ");
            fprintf(OUTPUT_PRINT, "%s", p->pipeInPath);
            exit(1);
        }
        else
        {
            fprintf(OUTPUT_PRINT, "    [CHILD] Open PIPE In OK.\n");
            fflush(OUTPUT_PRINT);
            PIPEIN = fdPipeIn;
        }
    }

#endif // USE_PIPES

//    unsigned edge_cb_id = 0;
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

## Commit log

2025-08-22 Ongoing aggravation with types - still seeing errors on ful build. .
    [i2c.c, magdata.c, main.c]
2025-09-08 Making changes to allow an i2cdetect type commandline option (-S) to list devices on a bus.
2025-10-06 Add signal handling and threads.
2025-10-07 Create udev .rules file and set the default device path.
2025-10-13 fix some incorrect messages.
    [main.c]
2025-10-19 fix some stupid SEGFAULT.
    [cmdmgr.c, config.c, magdata.c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]
2025-10-20 Fixed Mag reads, still not confident of values.
    [cmdmgr.c, i2c-pololu.c, magdata.c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]
2025-10-20 Still problem with mag polling
    [main.c]
2025-10-23 Fixed vexing buffer overflow. Tried to add device tests.
    [i2c-pololu.c, i2c-pololu.h, i2c.c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]
2025-10-24 Implemented better Pololu device/port checks, improved unit tests.
2025-10-24 Fixed verification of MCP9808 or MCP9804 Sensors, sterted code cleanup.
    [i2c-pololu.c, i2c.c, magdata.c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]
2025-11-23 Add warning for upcoming breaking change
    Added a warning about an upcoming breaking change regarding sensor temperature output.
2025-11-24 Remove warning about sensor temperature omission
    Removed warning about upcoming breaking change related to sensor temperature output.
2026-05-12 udev rule: also match PID 0x2502 (5396) and set group/mode
    The existing rule matched only PID 0x2503 (Pololu 5397 with isolated
    power) and created the /dev/ttyMAG0 symlink without explicit
    GROUP/MODE. The 5396 variant (same family, no isolated power, PID
    0x2502) was silently uncovered, and the symlink inherited the
    default cdc_acm perms which require sudo on most distros.
    Two narrow rules (one per PID) is clearer than ORing the values
    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
2026-05-12 main: fix magata.fifo typo (was magdata)
    main.c hardcoded fifoData = "/run/mag-usb/magata.fifo" (missing
    'd') as the default output-FIFO path when -DUSE_PIPES is set,
    while every other source of truth -- src/config.toml and
    docs/Configuration.md -- says /run/mag-usb/magdata.fifo. A user
    who relied on the global default rather than overriding via
    config.toml would create one pipe and read from a different one.
    Aligning the global default with the documented and config-file
    path makes the two converge.
    [main.c]
2026-05-12 main: default portpath /dev/ttyMAG0 to match udev symlink
    The previous default was /dev/ttyACM0, but install/99-PololuI2C.rules
    creates a /dev/ttyMAG0 symlink so the program would have a stable
    device path that survives replug. Once the rule is installed,
    /dev/ttyACM* renumbers freely and the documented default no longer
    points where the udev rule promised.
    Aligning the in-code default with the udev rule makes "install the
    rule, run with no -O flag" the happy path, and keeps -O /dev/ttyACMn
    working as an explicit override for hosts without the rule installed.
    Updated:
    - src/main.c portpath[] = "/dev/ttyMAG0"
    - src/config.toml portpath = "/dev/ttyMAG0"
    - README.md Quic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
    [main.c]
2026-05-12 main: align 1 Hz cadence to wall-clock with clock_nanosleep(TIMER_ABSTIME)
    print_data() previously did
    formatOutput(p);
    nanosleep({1, 0}, NULL);
    so each iteration's wakeup was 1 s after the *previous* one
    finished -- meaning the actual sample cadence drifted by however
    long the synchronous I2C round-trip in formatOutput() took (POLL
    write + busy-poll on DRDY + 9-byte XYZ read + MCP9808 temp read).
    Once accumulated drift exceeded one whole second, the matching UTC
    tick was silently skipped, producing the "occasional missed sample"
    behaviour reported in the field.
    This change anchors the wakeup on an absolute CLOCK_REALTIME
    deadline and advances by exactly +1 s after each successful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
    [main.c]
2026-05-12 main: block signals in calling thread before pthread_create
    The signal_handler_thread() worker installed via pthread_create()
    calls sigwait() on SIGHUP/SIGABRT/SIGINT to drive the graceful
    shutdown_requested handshake. For sigwait() to actually receive
    those signals the corresponding bits MUST be set in every thread's
    signal mask, because the kernel delivers an asynchronous signal to
    the *first* thread whose mask does not block it.
    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
2026-05-12 config: free pipe_in_path/pipe_out_path before strdup overwrite
    setProgramDefaults() in main.c initialises p->pipeInPath and
    p->pipeOutPath with strdup() of the compile-time defaults. When
    config.toml's [output] section overrode either path, the loader
    did
    p->pipeInPath = strdup(value);
    without freeing the previous allocation -- leaking the default
    strings every time the config file was loaded. The [websocket]
    bind_address branch already handled this correctly with a
    free()-before-strdup() pattern; the pipe paths now match.
    Practical leak per run is a few dozen bytes (the default FIFO
    paths), bounded -- but it triggers on every load_config() call,
    and main.c calls load_config() once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
    [config.c]
2026-05-12 i2c: snprintf instead of sprintf when formatting portpath errors
    i2c_open() formatted the portpath into a fixed 1024-byte errstr
    buffer with sprintf(). p->portpath is sourced from the -O CLI flag
    or config.toml [i2c] portpath = "..." key; both allow up to
    PATH_MAX (4096 on Linux) bytes. A portpath longer than ~1000 bytes
    would overflow the buffer. In practice paths are short, but
    snprintf() costs the same and is bounded.
    Also: defensive NULL-check on p->portpath in the format string so
    the diagnostic still prints something useful if a malformed config
    left it unset.
    [i2c.c]
2026-05-12 sensor_tests: use configured magAddr; distinct sentinel on version mismatch
    Two related issues in i2c_verifyMagSensor():
    1. The function hardcoded the I2C address as 0x23 ("example
    device" per the inline comment) even though pList->magAddr is
    populated from config.toml [magnetometer].address and is what
    the rest of the program actually talks to. A user who set a
    non-0x23 address would see -M succeed against a different
    device than the one the daemon uses, or fail spuriously.
    2. The version-mismatch arm returned the read byte itself:
    rv = buf[0];
    if(rv == (uint8_t)RM3100_VER_EXPECTED) return 0;
    else return rv;
    If the bus was dead (NACK + the adapter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
    [sensor_tests.c]
2026-05-12 i2c-pololu: size write_to cmd[] to 259 bytes; guard memcpy when size==0
    i2c_pololu_write_to() declared a 258-byte staging buffer for the
    adapter command frame (CMD_I2C_WRITE + address + length + reg +
    data). With size being uint8_t the data payload can be up to 255
    bytes, putting the worst-case framed length at 4 + 255 = 259 bytes
    -- one past the declared array. memcpy(&cmd[4], data, 255) would
    then write cmd[4..258] inclusive, of which cmd[258] is out of
    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
2026-05-12 docs+cli: -O help text and drdy_delay units now match the code
    Two stale-comment fixes:
    1. cmdmgr.c -h/-? help text still printed
    -O ... [ default: /dev/ttyACM0 ]
    after the earlier portpath default-change commit
    (3e366b1) made the actual default /dev/ttyMAG0.
    2. drdy_delay is documented in docs/Configuration.md and
    src/config.toml as "microseconds", but i2c.c does:
    usleep(p->DRDYdelay * 1000)
    which is ms -> us conversion. With the default 10 we wait
    ~10 ms between DRDY status polls -- which is appropriate
    for the RM3100's conversion time at CC=400, but a hundred
    thousand times longer than the docs imply. The code is
    doing the ri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
    [cmdmgr.c]
2026-06-02 Address PR issues from Mike, Rob, &Claude's second tranche.
    [cmdmgr.c, magdata.c, main.c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]
2026-06-11 Some edits to existing documentation files.
    [Pi Touch Display 2 Stand.stl, PiDisplay2-Small-panel.scad, PiDisplay3-Small-panel.3mf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]
2026-06-17 Some cleanup + some 3d Printing assets for documentation.
    [HDMI_plug_block.stl, HDMI_plug_block2.stl, HDMI_plug_block3.stl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]
2026-07-25 More secondary documentation assets and updates.
    [HDMI_plug_block6.3mf, HDMI_plug_block6.scad, rack_plate.scad]
2026-08-10 i2c_initMagSensor: program CC/NOS registers before starting sampling
    setCycleCountRegs() and setNOSReg() are defined but never called, so the
    RM3100 runs at its power-on cycle count while the xyz conversion divides
    by the configured gain (GAIN_150 default, or getCCGainEquiv(cc) when -c
    is given). Program the cycle-count and NOS registers - and derive the
    matching gains - in i2c_initMagSensor(), before the sampling mode is set.
    setCycleCountRegs() also writes the NOS register, so a separate
    setNOSReg() call is not needed here; it is left in place for standalone
    use.
    Fixes #8.
    [i2c.c]
2026-08-10 mqtt: verify the broker's TLS certificate
    SSL_CTX_new(TLS_client_method()) defaults to SSL_VERIFY_NONE, so
    use_tls encrypted the session but accepted any certificate - anything
    answering on the broker's address could terminate TLS, read telemetry,
    and issue device commands via the <topic>/command subscription.
    - SSL_CTX_set_verify(SSL_VERIFY_PEER) with the system trust store by
    default, or a CA bundle via the new [mqtt] ca_file config key /
    mqtt_client_set_ca_file() (covers self-signed / private-CA brokers)
    - SNI + hostname verification for name brokers, IP-SAN pinning for IP
    literals
    - explicit SSL_get_verify_result() check with a readable error message
    Addresses the TLS section of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
    [config.c, main.c, main.h]
2026-10-01 Document the MQTT ca_file setting added in #11
    #11 made the MQTT client verify the broker's TLS certificate and added an
    [mqtt] ca_file key, but no sample config or doc mentioned it. Stations with
    a self-signed or private-CA broker would fail to connect after upgrading
    with no documented fix.
    - install/config.toml: add ca_file = "" with guidance.
    - docs/Configuration.md: document ca_file and hostname/IP verification,
    and add it to the full example.
    - docs/Getting-Started.md: test.mosquitto.org uses its own CA (rejected by
    the system trust store), so download mosquitto.org.crt and set ca_file.
2026-10-01 Fix warnings that fail CI's clang and Ubuntu gcc builds
    The first CI run failed in every job on warnings the local Debian gcc build
    doesn't emit:
    - clang -Wstrict-prototypes: declare no-argument functions as (void) in
    i2c-pololu.h, main.h, main.c and the test functions.
    - clang -Wnewline-eof: src/config.h lacked a final newline.
    - Ubuntu gcc enables _FORTIFY_SOURCE, so ignored write() results warn:
    - main.c pipe output: still drops the sample line on failure, now
    explicitly.
    - test mock adapter: a short or failed write now fails the test via
    mock_write() instead of passing silently.
    - test timeout signal handler: result checked; it exits regardless.
    Verified with the CI matr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
    [i2c-pololu.h, main.c, main.h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]
2026-10-01 Keep the RM3100 gain exact instead of truncating it (fixes #14)
    getCCGainEquiv() cast 0.3671 * CC + 1.5 to unsigned short, so readings were
    divided by a truncated gain: ~0.23% high at CC 400 (148 vs 148.34) and ~1.2%
    at CC 200 (74 vs 74.92). #10 made this path live.
    - Return and store the gain as double (pList x/y/z_gain); print it with
    %.4f in -P, the debug trace and the MQTT config message.
    - Default gains derive from the default cycle count instead of GAIN_150.
    [magnetometer] gain_x/gain_y/gain_z were already overwritten by
    setCycleCountRegs() at sensor init since #10, and honouring them would
    reintroduce #8 (the samples shipped 150.0 for CC 400). They now print a
    warning that they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
    [cmdmgr.c, config.c, magdata.c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]
2026-10-21 Harden MQTT client against overflow, hangs and leaks
    - Build CONNECT and SUBSCRIBE on the heap, sized from their contents,
    with a variable-byte remaining-length encoder. Long credentials or
    topics no longer overflow the stack or truncate the length byte.
    - Bound blocking socket reads and writes with a 5 s timeout so a
    stalled broker cannot hang the caller.
    - Release socket and TLS state on every connect failure path, and let
    mqtt_client_free() clean up after a failed connect.
    - Detect closed connections and mid-packet failures in the poll and
    drop the connection, rather than silently ignoring them.
    - Read and discard unhandled packet types so the stream stays aligned.
    - Check the S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
2026-10-21 MQTT: support IPv6 brokers (fixes #15)
    mqtt_client_connect() used AF_INET and gethostbyname(), so it could only
    reach IPv4 brokers. It now resolves the name with getaddrinfo(AF_UNSPEC)
    and tries each address until one connects.
    - broker_address accepts an IPv6 literal in brackets, e.g. "[::1]".
    - TLS identity pinning treats IPv6 literals like IPv4 ones: the IP SAN
    is checked and SNI is skipped.
    - Document the accepted broker_address forms and add a CHANGES entry.
2026-10-21 WebSocket: match handshake headers case-insensitively (fixes #13)
    The vendored MengRao/websocket server compared request header names and
    Upgrade/Connection values with memcmp, so clients that send lowercase
    header names (Deno's WebSocket, most HTTP/2-era libraries) or token
    lists such as "Connection: keep-alive, Upgrade" were rejected with 400.
    - Compare header names with strncasecmp (length checked first).
    - Check Upgrade and Connection as case-insensitive token lists.
    - Document the vendored change in third_party/.../MAG_USB_CHANGES.md so
    it can be sent upstream; add a CHANGES entry.
2026-10-21 Add a local Mosquitto test broker for the MQTT client
    tests/mqtt/ sets up a broker on the test machine with TLS, a test CA,
    and per-role dynsec accounts (station, command issuer, viewer, probe).
    Scripts:
    - setup_broker.sh creates certs, config, accounts and roles under
    tests/mqtt/run/ (gitignored). It leaves the system Mosquitto alone.
    - broker.sh starts, stops and reports on the test broker.
    - acl_test.sh checks who can publish and subscribe where, and refuses
    anonymous clients. It passes 7 of 7.
    - mqtt_driver.c drives the real client code over TLS. It covers login,
    subscribe, publish, command receipt, and the failure cases (no CA,
    wrong password, broker dropped).
    The README cover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
2026-10-21 Include node_id in the MQTT configuration message
    Each station needs an identifier in the configuration message it publishes.
    The project's design calls for it, but the code never implemented it.
    - [node_information] node_id in config.toml, or -N <id> on the command line
    (the command line wins).
    - 1 to 65 printable ASCII characters. Spaces, double quotes and backslashes
    are refused, because the value is written into the JSON unescaped.
    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
2026-10-21 Build MQTT topics from node_id under hamsci/mag
    Stations now publish to a topic derived from their node_id:
    hamsci/mag/<node_id>/data samples
    hamsci/mag/<node_id>/data/command commands (get_config)
    hamsci/mag/<node_id>/config configuration message
    - [mqtt] topic_prefix (default hamsci/mag) replaces topic. An old topic
    key is ignored with a warning.
    - The configuration message moves to its own topic, so a subscriber to
    .../data gets only samples. Wildcard subscribers to +/data see one
    station's samples each.
    - MQTT does not start without a node_id, and says so.
    - node_id may not contain / + or #, since it becomes a topic level.
    The prefix is checked too.
    - Tes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
2026-10-22 Publish the configuration message retained
    The config message is now published with the retain flag, so a
    subscriber that connects after the station has started still gets the
    current configuration. Samples are unchanged.
    mqtt_client_publish() and the new mqtt_client_publish_retained() share
    one packet builder that takes the fixed-header byte.
2026-10-22 Clear retained config on shutdown and fix duplicate MQTT error
    - On clean shutdown, publish an empty retained message to the config
    topic so a stopped station's configuration no longer looks current.
    - Remove the generic "MQTT init failed" message from main; each failure
    in mqtt_init_client already reports its cause. Report the one silent
    failure, client allocation.
    - The ACL test clears any retained config before its checks, so a
    leftover message from an earlier run can't fail the viewer check.
